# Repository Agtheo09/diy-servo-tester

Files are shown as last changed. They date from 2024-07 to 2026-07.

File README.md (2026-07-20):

<div align="center">

# Ultimate Servo Tester V3 🛠️🚀
by **Agtheo09**



[]()
[]()
[]()
[]()
[]()
[]()

</div>

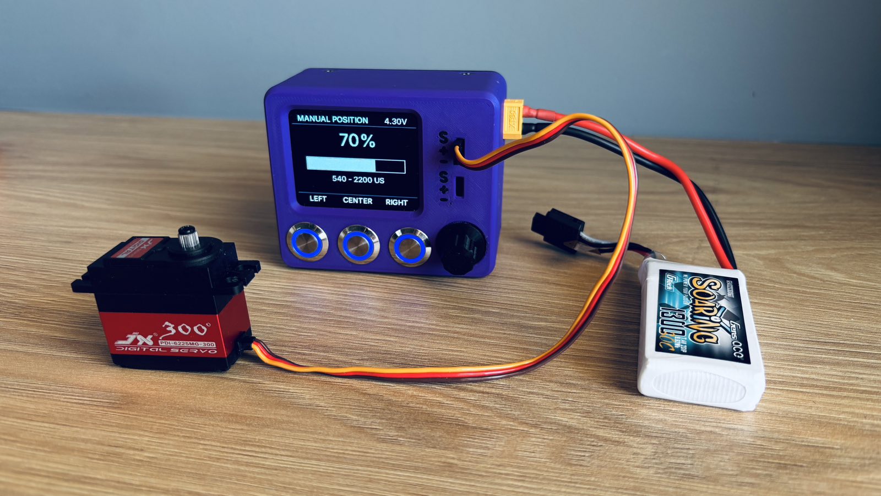
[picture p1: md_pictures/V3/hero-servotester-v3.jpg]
Ultimate Servo Tester V3


<div align="center">

<a href="https://cad.onshape.com/documents/18e5575c1bfbf00e07aefd84/w/2994546400e9325c3d562d8c/e/b3a9ed863121c41737853b93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" target="_blank">
  
</a>

</div>

The **Ultimate Servo Tester V3** is a high-performance, open-source diagnostic instrument designed for makers, engineers, and robotics competitors.

Driven by an **Arduino Nano**, this project represents a complete hardware redesign focused on:

- Field durability
- Universal power compatibility
- Fast graphical visualization
- Safe servo testing
- Modular repairable construction

Unlike standard commercial servo testers that only verify position, the V3 introduces advanced **Velocity Profiling** and a **Mechanical Boundary Capture Routine** to safely characterize servo behavior without risking damage to mechanical systems.

---

# 📸 System Overview

| Parameter | Specification |
| :--- | :--- |
| **Processor Core** | Arduino Nano (ATmega328P @ 16MHz) |
| **Display Panel**  | 2.4" 240×320 SPI Graphical LCD |
| **Bus Protocol** | Hardware SPI (Fast refresh rate) |
| **Control Input**  | Rotary encoder + dedicated buttons |
| **Form Factor** | Ultra-Compact layout (<80mm PCB footprint) |
| **BOM Cost** | Under €40 using standard components |
| **Assembly Time**  | Under 3 hours from bare PCB |

---

# 🔥 Key Engineering Features

## 1. Multi-Mode Advanced Control

### Absolute Position Mode

Direct servo positioning using a precision rotary encoder interface.

### Velocity Sweep Mode

Automated servo movement cycles with adjustable speed profiling to analyze:

- Transition smoothness
- Stall points
- Mechanical resistance
- Servo response characteristics

### Mechanical Boundary Capture (Keyframing)

The tester allows users to manually define safe mechanical limits.

This prevents accidental over-driving of servos installed inside:

- Robotic joints
- RC mechanisms
- Custom linkages
- Limited travel assemblies

---

# 2. Dual-Stage Hardware Protection Circuit

Most hobby servo testers expose the controller directly to servo faults.

The V3 architecture separates the logic and servo power domains using a protection-focused power design.

```
                     [Power Input]
                           |
              +------------+------------+
              |                         |
       [2A Glass Fuse]          [PTC Polyfuse]
              |                         |
      [LM2596S Buck]          [Servo Output Rails]
              |
      [Arduino Logic Core]
```

Protection layers:

### Primary Input Protection

**2A Fast-Blow Glass Fuse**

Provides immediate isolation during major electrical faults.

### Servo Bus Protection

**2A PTC Resettable Fuse**

Automatically limits current during:

- Servo stalls
- Wiring shorts
- Excessive mechanical loads

The logic controller remains protected and powered.

---

# 3. Universal Multi-Chemistry Power Management

The onboard power system supports common robotics battery configurations.

Supported inputs:

- **2S - 3S LiPo**
  - 7.4V - 11.1V

- **6S - 10S NiMH**
  - 7.2V - 12V

- **8V - 12V DC Supply**
  - Via screw terminals

---

# 📈 Architectural Evolution

The V3 design is the result of multiple hardware iterations focused on improving usability, protection, and performance.

| Attribute | V1 | V2 | V3 |
| :--- | :--- | :--- | :--- |
| Interface | 16x2 Character LCD | 16x2 Character LCD | **2.4" SPI Graphical LCD** |
| Control | Raw position control | Position + center + velocity | **Position + velocity + boundary capture** |
| Communication | Parallel interface | I2C | **Hardware SPI** |
| Protection | None | Basic filtering | **Glass Fuse + Servo PTC Protection** |
| Power | Barrel jack only | Limited supply options | **LiPo / NiMH / Bench Supply Compatible**  |

---

# 🗂️ Repository Organization

```
.
├── software/
│   ├── main/                 # Main Arduino firmware
│   ├── tests/                # Hardware validation sketches
│   └── font-optimization/    # Display font generation tools
│
├── hardware/
│   ├── pcb/                  # PCB fabrication files and 3D models
│   ├── stl_files/            # 3D printable enclosure components
│   └── SCHEMATIC_UltimateServoTester.pdf
│
├── md_pictures/              # Documentation images
│
└── README.md
```

---

# 🧩 Hardware Bill of Materials (BOM)

The V3 hardware philosophy is based on:

- Standard off-the-shelf components
- Easy hand assembly
- Repairability
- No proprietary modules

---

# 🏗️ Mechanical Components

| Qty  | Component | Purpose |
| :--- | :--- | :--- |
| 1x | [3D Printed Components](hardware/stl_files) | Custom enclosure parts, covers, and mechanical interfaces |

Included models:

- Case for 12mm buttons
- Case for 16mm buttons
- Encoder knob
- LCD cover
- Nut covers
- Thread insert covers

---

# 🔌 PCB & Power Components

The V3 power system follows the dual-stage protection philosophy.

| Qty  | Component | Purpose |
| :--- | :--- | :--- |
| 1x | [Custom PCB](hardware/pcb) | Main controller and power distribution |
| 1x | XT60 Round PCB Connector | Battery input |
| 2x | 5mm Pitch Dual Screw Terminal | External power connections |
| 1x | 5×20mm Glass Fuse PCB Mount | Primary fuse holder |
| 1x | 2A Fast-Blow Glass Fuse | Main power protection |
| 1x | 2A PTC Resettable Fuse | Servo bus protection |
| 1x | LM2596S Buck Converter | Logic power regulation |

---

# 🧠 Controller & User Interface

| Qty  | Component | Purpose |
| :--- | :--- | :--- |
| 1x | Arduino Nano | Main processing unit |
| 1x | [2.4" SPI LCD](https://grobotronics.com/display-2.4-240x320-lcd-module.html) | Graphical user interface |
| 1x | Rotary Encoder | Menu navigation |
| 3x | Metal Push Buttons | User controls |
| 1x | 5V Passive Buzzer | Feedback indicator |

---

# 🔩 Passive Components

| Qty  | Component | Specification |
| :--- | :--- | :--- |
| 1x | Resistor | 10kΩ 1/4W |
| 1x | Resistor | 4.7kΩ 1/4W |
| 1x | Resistor | 47Ω 1/4W |
| 1x | Ceramic Capacitor | 100nF |
| 1x | Ceramic Capacitor | 100µF |
| 1x | Ceramic Capacitor | 470µF |

---

# 🔗 Connectors

| Qty  | Component | Specification |
| :--- | :--- | :--- |
| ~8x  | Male Headers | 2.54mm pitch |
| 5x | JST HX Connector Sets | 4-pin male + female |
| 1x | JST HX Connector Set  | 5-pin male + female |

---

# 💰 Estimated Build Cost

| Category | Estimated Cost |
| :--- | :--- |
| PCB | Depends on manufacturer |
| Components | ~€30-35 |
| 3D Printed Parts | Depends on material |
| Complete Device  | **< €40 target** |

---

# 🚀 Quick Start Guide

## 1. Manufacture PCB

Use the fabrication files located in:

```
hardware/pcb/
```

The folder contains:

- Gerber package
- PCB previews
- Mechanical STEP files

---

## 2. Assemble Components

Populate the PCB by following the component footprints and silkscreen markings on the board.

Component placement is designed to be straightforward with clear PCB references for:

- Through-hole components
- Connectors
- Protection devices
- User interface hardware

The schematic is provided for electrical reference and troubleshooting:

```
hardware/SCHEMATIC_UltimateServoTester.pdf
```

Assembly should primarily follow the PCB footprint layout and silkscreen labels.

---

## 3. Upload Firmware

Open:

```
software/main/main.ino
```

Required:

- Arduino IDE
- Arduino Nano board definition
- Required display libraries

---

# 🤝 Open Source & Contributions

This project is fully open source.

Anyone can:

- Build the tester
- Modify the hardware
- Improve firmware
- Create new enclosure designs
- Submit improvements

Hardware optimization forks and pull requests are welcome.

---

# 📄 License

This project is licensed under the MIT License.

See:

```
LICENSE
```

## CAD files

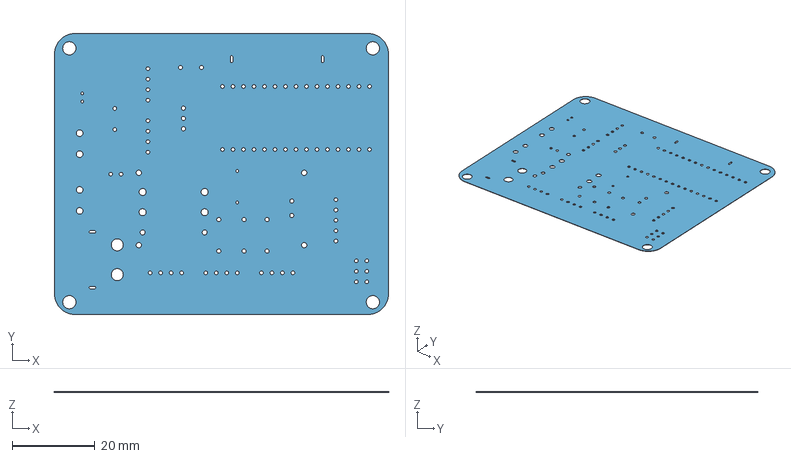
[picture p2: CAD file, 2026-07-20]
hardware/pcb/3D_PCB_UltimateServoTester_BARE.step
80.8 x 68.0 x 0.09 mm
Board~IHJW
TopCopper~IHJW
BottomCopper~IHJW
TopSilkscreen~IHJW
BottomSilkscreen~IHJW
TopFpcStiffener~IHJW
BottomFpcStiffener~IHJW

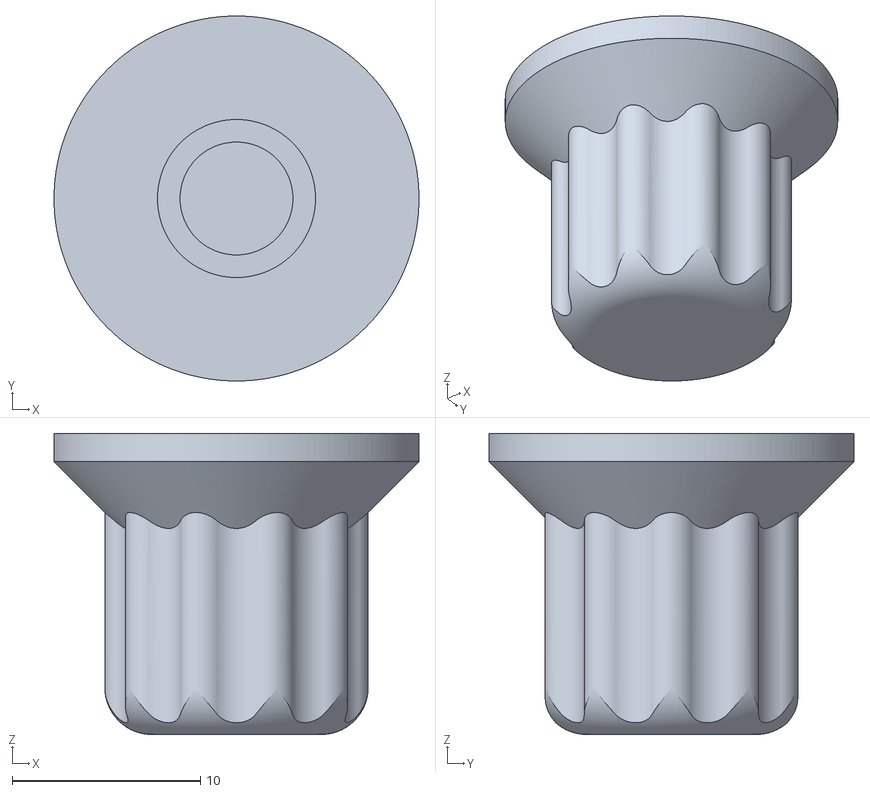
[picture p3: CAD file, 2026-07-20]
hardware/stl_files/EncoderKnob.stl
19.4 x 19.4 x 16.0

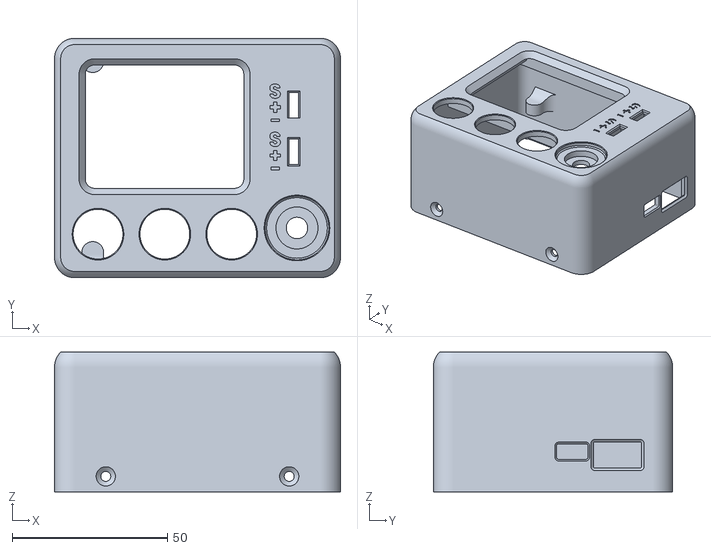
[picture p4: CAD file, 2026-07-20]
hardware/stl_files/Case16mmMetalButtons.stl
92.0 x 77.0 x 45.0

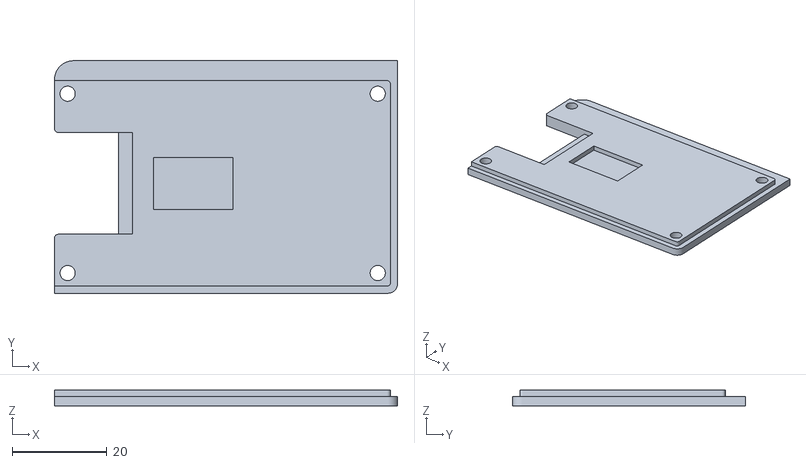
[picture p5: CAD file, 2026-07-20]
hardware/stl_files/LCDCover.stl
72.5 x 49.1 x 3.30

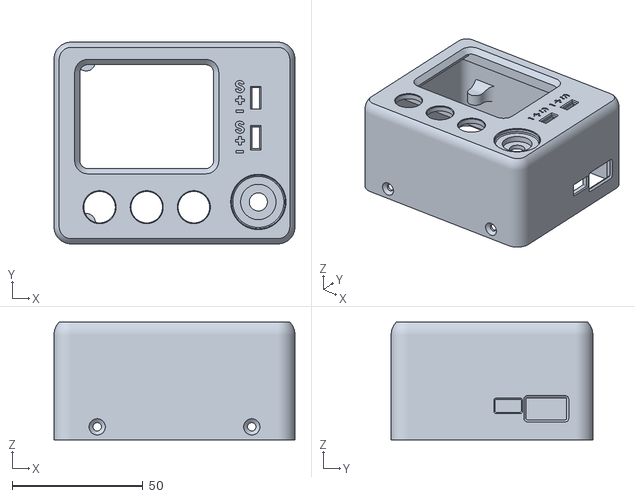
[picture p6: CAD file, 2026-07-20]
hardware/stl_files/Case12mmMetalButtons.stl
92.0 x 77.0 x 45.0

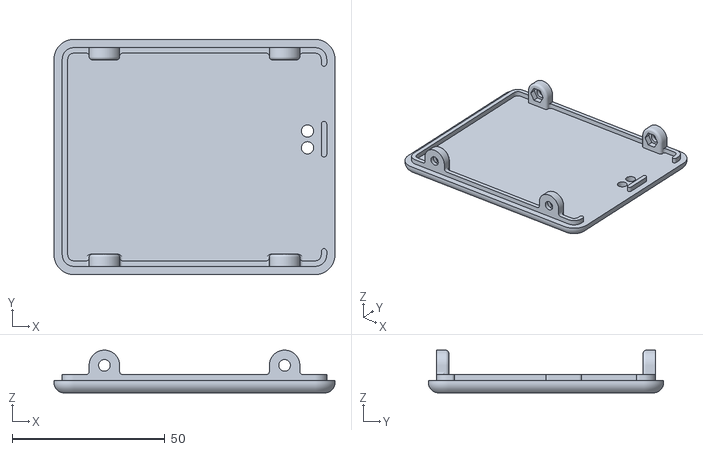
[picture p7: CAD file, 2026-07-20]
hardware/stl_files/LidForNuts.stl
92.0 x 77.0 x 14.0

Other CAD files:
hardware/stl_files/LidForThreadedInserts.stl

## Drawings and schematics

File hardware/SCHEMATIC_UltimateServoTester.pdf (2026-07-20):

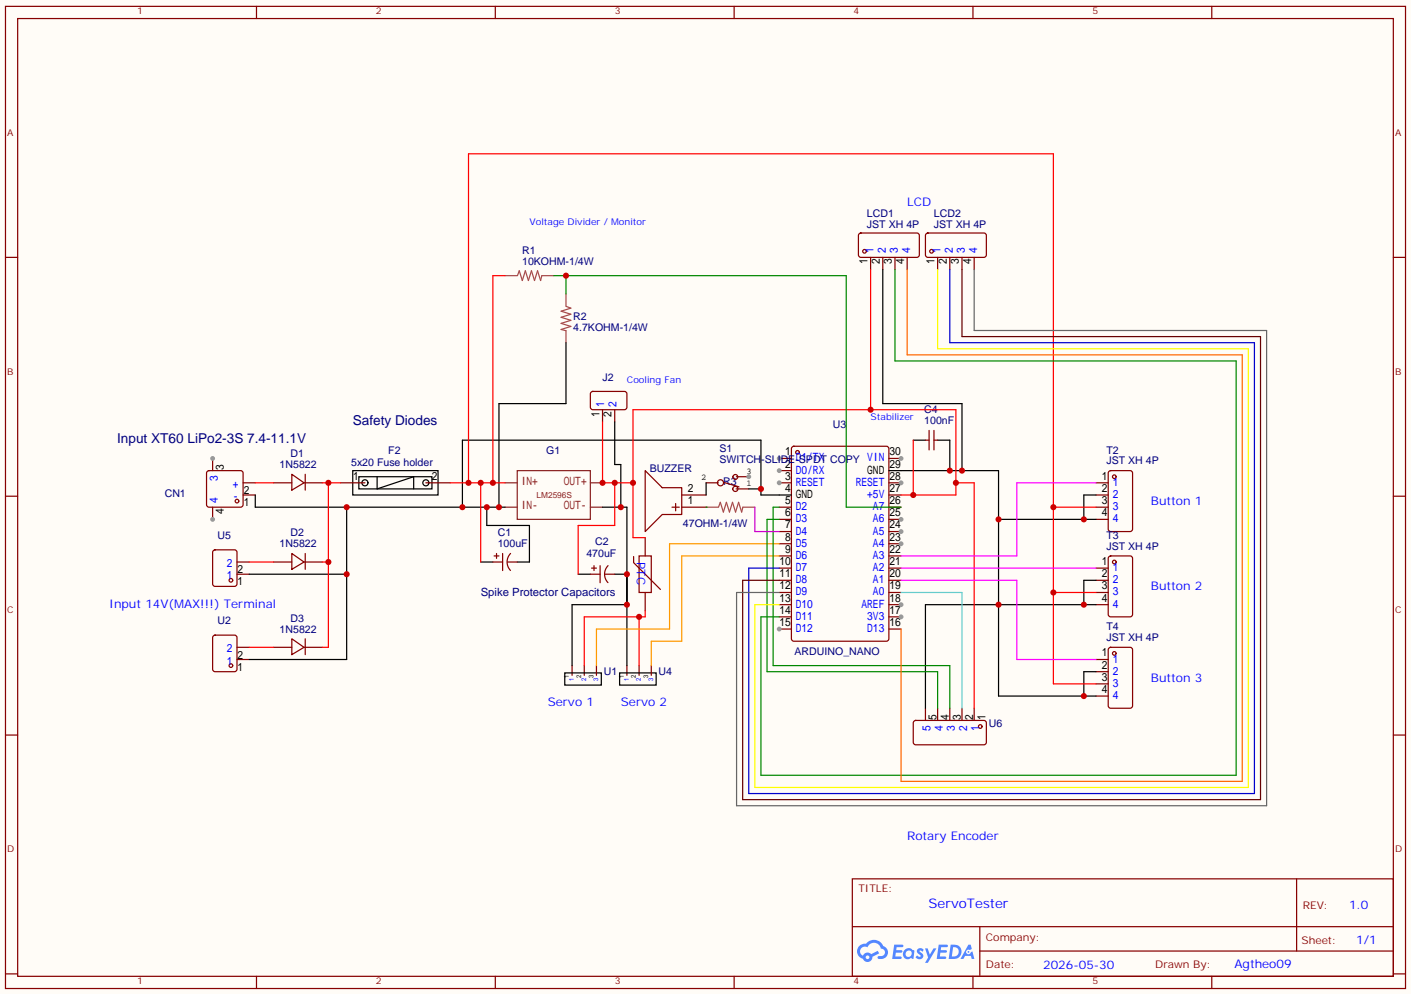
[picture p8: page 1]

Stabilizer Safety Diodes 100nF

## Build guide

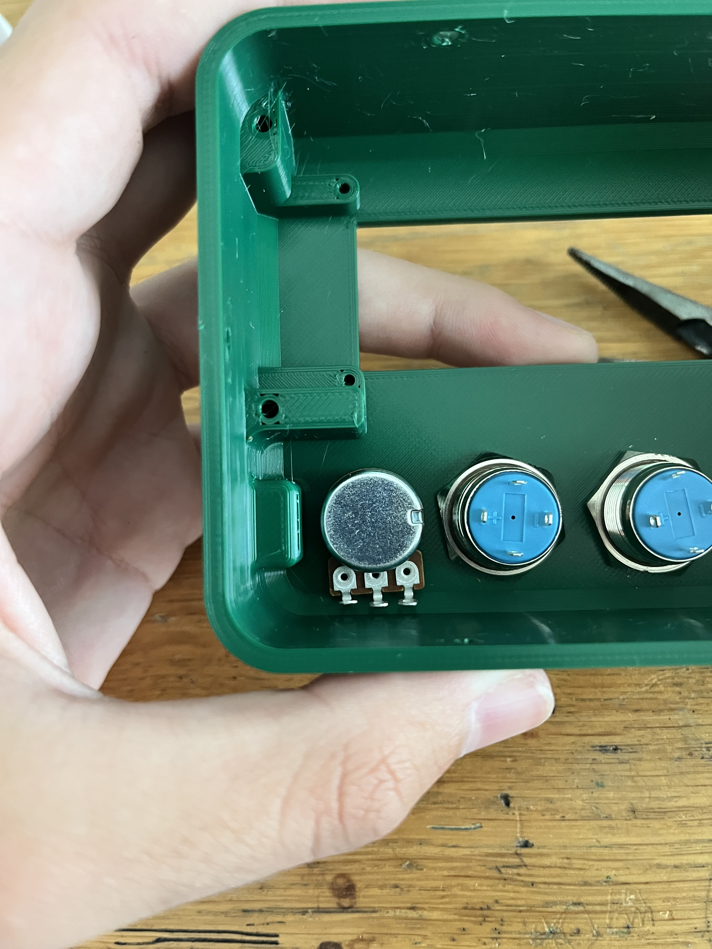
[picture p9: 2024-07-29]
md_pictures/steps/step03/iii/image00027.jpeg

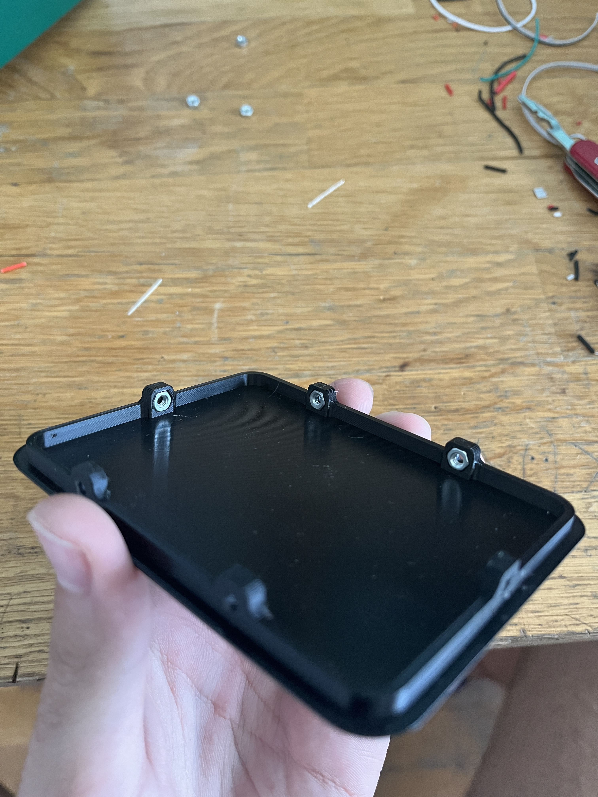
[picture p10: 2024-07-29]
md_pictures/steps/step24/image00002.jpeg

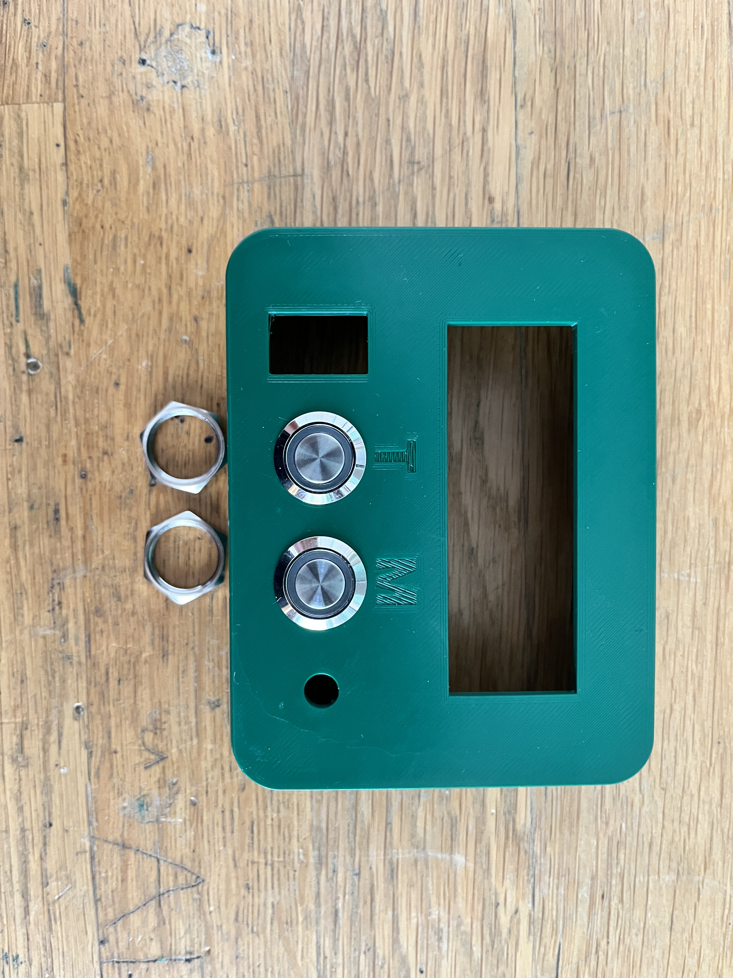
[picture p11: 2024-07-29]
md_pictures/steps/step03/ii/image00029.jpeg

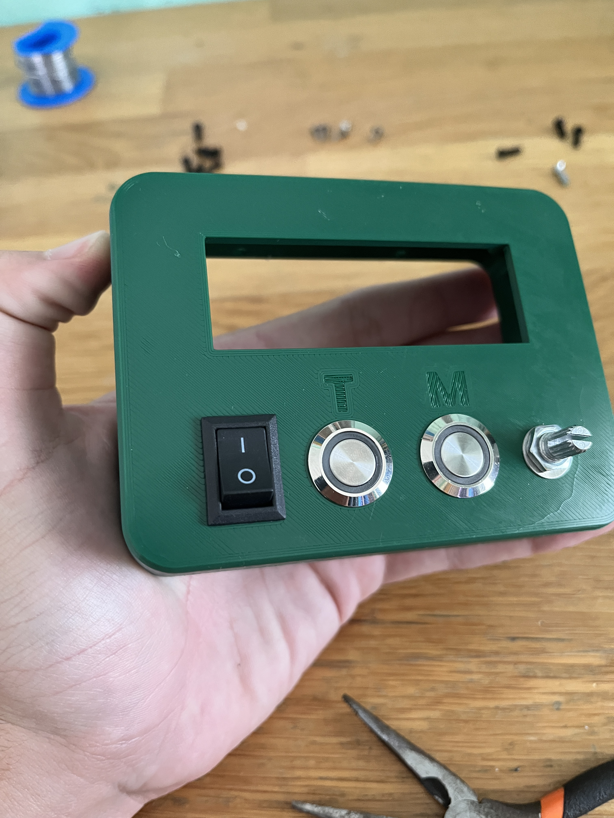
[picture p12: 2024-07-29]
md_pictures/steps/step03/iv/image00025.jpeg

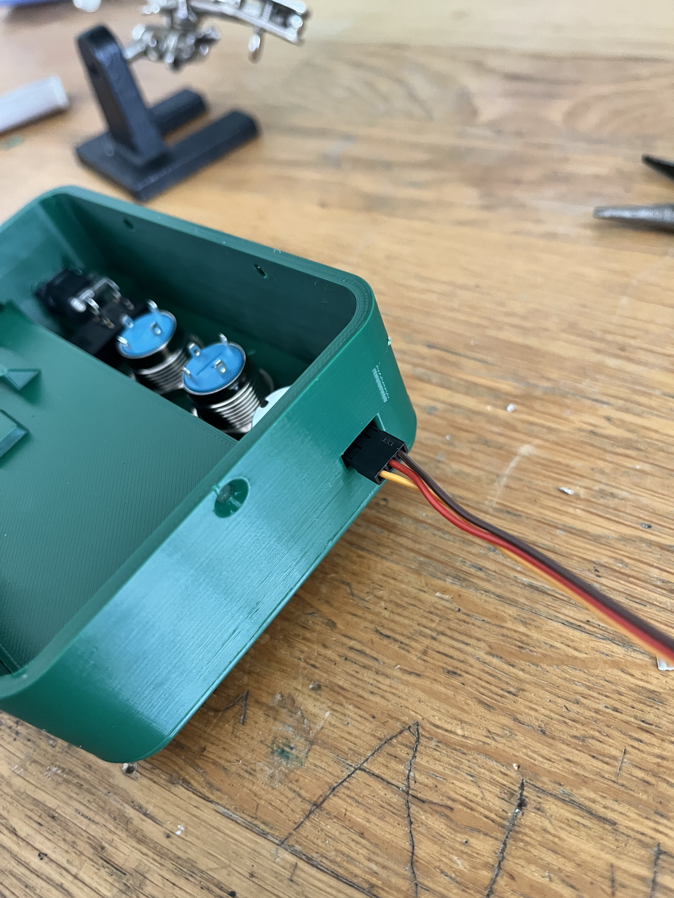
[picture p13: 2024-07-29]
md_pictures/steps/step09/image00015.jpeg

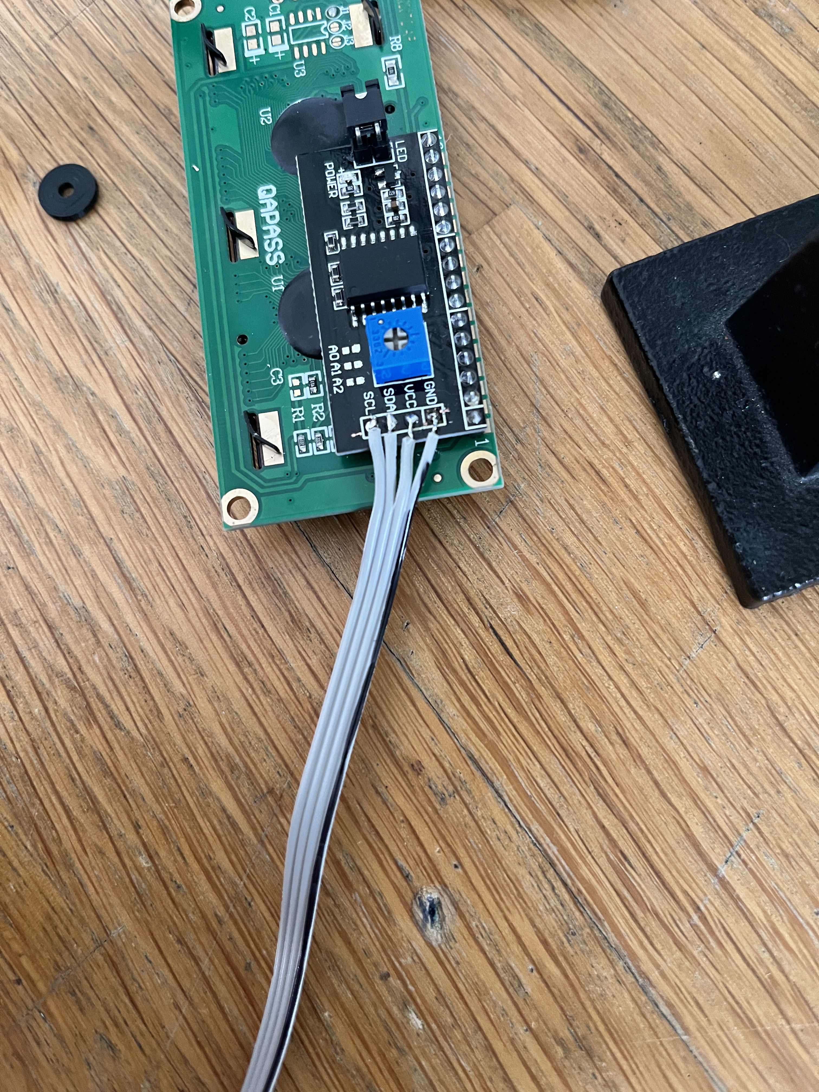
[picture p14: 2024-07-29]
md_pictures/steps/step05/ii/image00022.jpeg

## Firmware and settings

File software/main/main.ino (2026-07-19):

#include <Servo.h>
#include <Encoder.h>
#include "Button.h"
#include "BatteryMonitor.h"
#include "ServoController.h"
#include "DisplayManager.h"

#define DEBUG_TELEMETRY 1 

#define ENCODER_CLK_PIN 3
#define ENCODER_DT_PIN 2
#define ENCODER_SW_PIN A0
#define BUTTON_1_PIN A1
#define BUTTON_2_PIN A2
#define BUTTON_3_PIN A3
#define BUZZER_PIN 4
#define SERVO_1_PIN 5
#define SERVO_2_PIN 6
#define VOLTAGE_PIN A7

#define TFT_CS   10
#define TFT_DC   7   
#define TFT_RST  8
#define TFT_BL   9

Button button1(BUTTON_1_PIN);
Button button2(BUTTON_2_PIN);
Button button3(BUTTON_3_PIN);
Button encoderSwitch(ENCODER_SW_PIN);
BatteryMonitor battery(VOLTAGE_PIN, 300, 0.08); 
ServoController myServo1(SERVO_1_PIN, 540, 2200);
ServoController myServo2(SERVO_2_PIN, 540, 2200);
DisplayManager display(TFT_CS, TFT_DC, TFT_RST, TFT_BL);

Encoder myHardwareEnc(ENCODER_CLK_PIN, ENCODER_DT_PIN);
long lastNormalizedPos = 0;

enum SystemState { INIT_MENU, TEST_SELECTION_MENU, MANUAL_POSITION, NEUTRAL_POSITION, VELOCITY_TEST, STAMPS };
SystemState currentSystemState = INIT_MENU;

int activeMenuRow = 0;       
int activeTestMenuRow = 0;   
int configInputType = 0;   // 0=PWR SUP, 1=LiPo, 2=NiMH
int configCellCount = 0;   
int configServoRange = 0; 
int configOutputCount = 1; 

const int ENCODER_STEP = 2;
int encoderValue = 50;    
int currentGlobalMode = 0;

static float sweepValue = 0.0;
static int sweepDirection = 1;
static unsigned long lastSweepTick = 0;

void setup()
{
  #if DEBUG_TELEMETRY
    Serial.begin(9600);
  #endif
  
  button1.init();
  button2.init();
  button3.init();
  encoderSwitch.init();
  display.init();

  pinMode(BUZZER_PIN, OUTPUT);
}

void loop()
{
  battery.update();

  long currentNormalizedPos = myHardwareEnc.read() / 4; 
  int delta = currentNormalizedPos - lastNormalizedPos;
  lastNormalizedPos = currentNormalizedPos;

  if (currentSystemState == INIT_MENU) 
  {
    if (delta != 0) {
      if (delta > 0) {
        activeMenuRow++;
        if (configInputType == 0 && activeMenuRow == 1) activeMenuRow = 2;
      } else {
        activeMenuRow--;
        if (configInputType == 0 && activeMenuRow == 1) activeMenuRow = 0;
      }
      if (activeMenuRow > 4) activeMenuRow = 4;
      if (activeMenuRow < 0) activeMenuRow = 0;
    }

    if (encoderSwitch.isPressed()) {
      
      if (activeMenuRow == 0) { 
        configInputType++;
        if (configInputType > 2) configInputType = 0;
        
        if (configInputType == 1)      configCellCount = 2; 
        else if (configInputType == 2) configCellCount = 6; 
        else                           configCellCount = 0;
        beep(); 
      } 
      else if (activeMenuRow == 1) { 
        if (configInputType == 1) { 
          configCellCount = (configCellCount == 2) ? 3 : 2;
        } 
        else if (configInputType == 2) { 
          configCellCount++;
          if (configCellCount > 10) configCellCount = 6;
        }
        beep();
      }
      else if (activeMenuRow == 2) { 
        configServoRange = !configServoRange; 
        beep(); 
      } 
      else if (activeMenuRow == 3) { 
        configOutputCount = !configOutputCount;
        beep();
      }
      else if (activeMenuRow == 4) { 
        beep(); delay(60); beep();
        
        if (configServoRange == 0) {
          myServo1.setPulseRange(540, 2200);
          myServo2.setPulseRange(540, 2200);
        } else {
          myServo1.setPulseRange(500, 2500);
          myServo2.setPulseRange(500, 2500);
        }

        display.clearScreen(); 
        activeTestMenuRow = 0;
        currentSystemState = TEST_SELECTION_MENU;
        return;
      }
    }
    display.updateMenu(activeMenuRow, configInputType, configCellCount, configServoRange, configOutputCount);
  } 
  else if (currentSystemState == TEST_SELECTION_MENU)
  {
    if (delta != 0) {
      if (delta > 0) activeTestMenuRow++;
      else           activeTestMenuRow--;
      if (activeTestMenuRow > 3) activeTestMenuRow = 3;
      if (activeTestMenuRow < 0) activeTestMenuRow = 0;
    }

    if (encoderSwitch.isPressed()) {
      beep(); delay(60); beep();
      display.clearScreen();

      myServo1.init();
      if (configOutputCount == 1) {
        myServo2.init();
      }

      if (activeTestMenuRow == 0) {
        currentSystemState = MANUAL_POSITION;
        encoderValue = 50; 
      } 
      else if (activeTestMenuRow == 1) {
        currentSystemState = NEUTRAL_POSITION;
        encoderValue = 50; 
      } 
      else if (activeTestMenuRow == 2) {
        currentSystemState = VELOCITY_TEST;
        encoderValue = 25; 
        sweepValue = 0.0;
        sweepDirection = 1;
      }
      else if (activeTestMenuRow == 3) {
        currentSystemState = STAMPS;
        encoderValue = 50;
      }
      return;
    }
    display.updateTestSelectionMenu(activeTestMenuRow);
  }
  else 
  {
    static unsigned long buttonTimer = 0;
    static bool buttonActive = false;
    static bool longPressTriggered = false;

    if (digitalRead(ENCODER_SW_PIN) == LOW) {
      if (!buttonActive) {
        buttonActive = true;
        buttonTimer = millis();
        longPressTriggered = false;
      } 
      else if (!longPressTriggered && (millis() - buttonTimer > 400)) {
        longPressTriggered = true;
        
        currentSystemState = TEST_SELECTION_MENU;
        activeTestMenuRow = 0; 

        beep(); delay(60); beep(); 
        display.clearScreen();
        return; 
      }
    } 
    else {
      if (buttonActive) {
        buttonActive = false;
      }
    }

    int servoOutputValue = 50;

    if (currentSystemState == MANUAL_POSITION) 
    {
      if (delta != 0) encoderValue += (delta * ENCODER_STEP);
      if (encoderValue > 100) encoderValue = 100;
      if (encoderValue < 0)   encoderValue = 0;

      if (button1.isPressed()) { encoderValue = 0; beep(); }   // LEFT
      if (button2.isPressed()) { encoderValue = 50; beep(); }  // CENTER
      if (button3.isPressed()) { encoderValue = 100; beep(); } // RIGHT
      
      servoOutputValue = encoderValue;
    } 
    else if (currentSystemState == STAMPS)
    {
      if (delta != 0) encoderValue += (delta * ENCODER_STEP);
      if (encoderValue > 100) encoderValue = 100;
      if (encoderValue < 0)   encoderValue = 0;
      
      servoOutputValue = encoderValue;
    }
    else if (currentSystemState == NEUTRAL_POSITION) 
    {
      encoderValue = 50; 
      servoOutputValue = 50;
    }
    else if (currentSystemState == VELOCITY_TEST)
    {
      if (delta != 0) encoderValue += (delta * ENCODER_STEP);
      if (encoderValue > 100) encoderValue = 100;
      if (encoderValue < 0)   encoderValue = 0;

      if (button1.isPressed()) { encoderValue = 15; beep(); }   // SLOW Sweep Speed (15%)
      if (button2.isPressed()) { encoderValue = 50; beep(); }   // MID Sweep Speed (50%)
      if (button3.isPressed()) { encoderValue = 100; beep(); }  // FAST Sweep Speed (100%)

      if (encoderValue > 0) {
        if (millis() - lastSweepTick >= 15) {
          lastSweepTick = millis();
          
          float stepSize = (float)encoderValue * 0.03;
          if (stepSize < 0.05) stepSize = 0.05; 

          sweepValue += ((float)sweepDirection * stepSize);
          
          if (sweepValue >= 100.0) { sweepValue = 100.0; sweepDirection = -1; }
          else if (sweepValue <= 0.0) { sweepValue = 0.0; sweepDirection = 1; }
        }
      }
      servoOutputValue = (int)sweepValue;
    }

    // MODIFIED: Restructured Button 3 handling logic to intercept presses during STAMPS mode
    if (button3.isPressed()) {
      if (currentSystemState == STAMPS) {
        // Toggle mode strictly between 0 and 1 to flip the visual header text state cleanly
        currentGlobalMode = (currentGlobalMode == 0) ? 1 : 0;
        beep();
      }
      else if (currentSystemState != MANUAL_POSITION && currentSystemState != VELOCITY_TEST) {
        // Run standard operating logic for non-excluded test modes
        currentGlobalMode++;
        if (currentGlobalMode > 2) currentGlobalMode = 0;
        myServo1.setMode(currentGlobalMode);
        if (configOutputCount == 1) myServo2.setMode(currentGlobalMode);
        beep(); delay(50); beep();
      }
    }

    myServo1.update(servoOutputValue);
    if (configOutputCount == 1) {
      myServo2.update(servoOutputValue);
    }

    display.updateTestScreen(encoderValue, currentGlobalMode, battery.getVoltage(), configServoRange, (int)currentSystemState);
    
    #if DEBUG_TELEMETRY
      printTelemetry();
    #endif
  }
}

void beep()
{
  digitalWrite(BUZZER_PIN, HIGH);
  delay(30);
  digitalWrite(BUZZER_PIN, LOW);
}

void printTelemetry()
{
  #if DEBUG_TELEMETRY
    Serial.print("V: ");
    Serial.print(battery.getVoltage(), 2);
    Serial.print(" | S: ");
    Serial.print(currentSystemState);
    Serial.print(" | E: ");
    Serial.println(encoderValue);
  #endif
}

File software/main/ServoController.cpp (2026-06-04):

#include "ServoController.h"

ServoController::ServoController(int servoPin, int minP, int maxP)
{
    pin = servoPin;
    minPulse = minP;
    maxPulse = maxP;
    mode = 0;
    previousMillis = 0;
    swipeInterval = 10;
    currentPulse = (minP + maxP) / 2;
    swipeDirection = 1;
}

void ServoController::init()
{
    servo.attach(pin);
}

void ServoController::setMode(int newMode)
{
    if (newMode >= 0 && newMode <= 3)
    {
        mode = newMode;
    }
}

void ServoController::setPulseRange(int minP, int maxP)
{
    minPulse = minP;
    maxPulse = maxP;
    currentPulse = (minP + maxP) / 2; // Recenter the servo safely
}

int ServoController::getMode()
{
    return mode;
}

void ServoController::update(int encoderValue)
{
    switch (mode)
    {
    case 0: // MODE 0: Position Mode (Follows the encoder)
    {
        int pulseWidth = map(encoderValue, 0, 100, minPulse, maxPulse);
        servo.writeMicroseconds(pulseWidth);
        break;
    }

    case 1: // MODE 1: Neutral Mode (Locks to exact center)
    {
        int neutralPulse = (minPulse + maxPulse) / 2;
        servo.writeMicroseconds(neutralPulse);
        break;
    }

    case 2: // MODE 2: Swiping Mode (Automated back-and-forth using millis)
    {
        unsigned long currentMillis = millis();
        if (currentMillis - previousMillis >= swipeInterval)
        {
            previousMillis = currentMillis;

            currentPulse += (swipeDirection * 8);

            if (currentPulse >= maxPulse)
            {
                currentPulse = maxPulse;
                swipeDirection = -1;
            }
            else if (currentPulse <= minPulse)
            {
                currentPulse = minPulse;
                swipeDirection = 1;
            }

            servo.writeMicroseconds(currentPulse);
        }
        break;
    }
    case 3: // MODE 3:
    {
        // TODO
        break;
    }
    }
}

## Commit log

2024-07-22 First Schematic
    [schematic_project.fzz]
2026-06-01 Voltage Monitor Debugging
2026-06-02 All but screen in main and fixed tests
    [main.ino, rotary_encoder_test.ino]
2026-06-05 Voltage Monitor ++ Full GUI with Menus -- STAMPS
2026-07-20 README and Hardware added
    [3D_PCB_UltimateServoTester_BARE.step, Case12mmMetalButtons.stl, Case16mmMetalButtons.stl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]

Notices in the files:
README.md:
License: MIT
